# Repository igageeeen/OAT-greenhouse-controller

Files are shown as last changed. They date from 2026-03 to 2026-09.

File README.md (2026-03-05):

# ビニールハウス自動開閉制御システム

Raspberry Pi + Home Assistant を使ったビニールハウス開閉器の制御システムです。
スマートフォンから遠隔操作でき、温湿度・CO2 を常時モニタリングできます。

> **2026-03-01 メイカーズ長岡まつり 展示作品**
> OpenAgriTech

---

## 概要

| 項目 | 内容 |
|---|---|
| プラットフォーム | Raspberry Pi OS (Trixie) |
| UI | Home Assistant (Docker) |
| 外部公開 | Cloudflare Tunnel |
| センサ | SEN0501（温湿度）、SCD41（CO2・温湿度） |
| モータドライバ | Cytron MDD10 |
| モータ制御 | PWM 20kHz（GPIO18）+ 方向制御（GPIO23） |

---

## システム構成

```
スマートフォン
    ↓ HTTPS
Cloudflare Tunnel
    ↓
Home Assistant（Docker, host network）
    ↓ REST API（127.0.0.1）
┌───────────────────┬──────────────────────┐
│ metrics_server.py │   motor_server.py    │
│   :8124           │   :8125              │
│   温湿度・CO2取得  │   モータ開閉制御      │
└────────┬──────────┴──────────┬───────────┘
         │ I2C                 │ GPIO / PWM
    SEN0501 / SCD41         MDD10 → モータ
```

---

## ファイル構成

```
.
├── README.md                          # このファイル
├── docs/
│   ├── PARTS_LIST.md                  # パーツリスト（BOM）
│   └── SETUP.md                       # セットアップ手順
└── src/
    ├── metrics_server.py              # 環境センサ HTTP サーバ（:8124）
    ├── motor_server.py                # モータ制御 HTTP サーバ（:8125）
    ├── HomeAssistantConfiguration.yaml# Home Assistant 設定
    ├── SPEC.md                        # システム仕様書（詳細）
    └── ROM_USB_MIGRATION_PLAN.md      # SDカードROM化・USB分離計画
```

---

## 主な機能

- **遠隔開閉操作**: スマートフォンから「開く」「閉じる」「停止」ボタン操作
- **動作時間・出力の調整**: UI スライダーで秒数（1〜900秒）と PWM duty（0〜100%）を設定
- **環境モニタリング**: 温度・湿度（SEN0501）、CO2・温度・湿度（SCD41）を 30 秒間隔で取得
- **フェイルセーフ**: 最大 900 秒制限・ロックファイルによる二重起動防止・緊急停止 API

---

## セットアップ

詳細は [docs/SETUP.md](docs/SETUP.md) を参照してください。

### 必要なパーツ

[docs/PARTS_LIST.md](docs/PARTS_LIST.md) を参照してください。

### 依存ライブラリ（Python）

```bash
sudo pip install RPi.GPIO adafruit-circuitpython-scd4x dfrobot-environmental-sensor --break-system-packages

```

### サービス起動（systemd）

```bash
# metrics_server を登録・起動
sudo systemctl enable metrics_server
sudo systemctl start metrics_server

# motor_server を登録・起動
sudo systemctl enable motor_server
sudo systemctl start motor_server
```

---

## ネットワーク設計

- Home Assistant と各サーバはすべて `127.0.0.1` で通信
- LAN の IP アドレス変更やテザリング切り替えに依存しない設計
- 外部公開は Cloudflare Tunnel のみ（ポート開放不要）

---

## 耐障害性（ROM化・USB分離）

電源断を前提とした農業現場での運用のため、以下の対策を実施しています：

- root を `ro`（読み取り専用）でマウントし SD カードへの書き込みをゼロに
- journald を volatile（メモリのみ）、`/tmp` を tmpfs に
- Docker データ・Home Assistant DB・cloudflared データを USB フラッシュメモリへ分離
- 詳細: [src/ROM_USB_MIGRATION_PLAN.md](src/ROM_USB_MIGRATION_PLAN.md)

---

## ライセンス

MIT License

---

## 作成について

本プロジェクトのコード・ドキュメントは、**Claude（Anthropic 社製 AI アシスタント）の支援を受けて作成**しました。

- コード生成・レビュー・ドキュメント整備に Claude Code（claude-sonnet-4-6）、chatGPT5.2を使用
- 設計方針・要件定義・最終確認は人間（iga）が行っています

> *AI を農業 × ものづくりにどう活かすか、という実験でもあります。*

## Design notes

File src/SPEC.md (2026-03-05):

# ハウス開閉器システム仕様書

最終更新: 2026-02-23 08:42:50

------------------------------------------------------------------------

## 1. システム概要

本システムは Raspberry Pi 上で動作する
ハウス（ビニールハウス）開閉制御装置である。

Home Assistant を UI とし、 ローカル Python HTTP サーバ経由で

-   モータ制御
-   環境センサ取得

を行う。

外部公開は Cloudflare Tunnel 経由。

------------------------------------------------------------------------

## 2. 全体構成

\[スマホ\]\
　↓ (Cloudflare)\
\[Home Assistant (Docker, host network)\]\
　↓ REST\
\[motor_server.py :8125\]\
\[metrics_server.py :8124\]\
　↓\
\[Raspberry Pi GPIO / I2C\]

------------------------------------------------------------------------

## 3. 動作環境

-   Raspberry Pi OS (Trixie) ※2025年以降の標準リリース
-   Docker (Home Assistant)
-   network_mode: host
-   systemd 管理サービス
-   journald ログ最小化
-   ROM化済み（root ext4 を `ro` マウント、Docker・HA・cloudflared データは USB へ分離）

### GPIO / PWM 方式について

#### なぜ pigpio を使わないのか

Trixie（Pi5）環境では `pigpio` が**実質使用不可**であり、複数の問題が重なっている：

| 問題 | 技術的背景 |
|---|---|
| **Pi 5 でハードコード除外** | Pi5 は BCM2712 + RP1 サウスブリッジ構成。GPIO を管理するのは RP1 で、pigpio が依存する `/dev/mem` 経由の DMA アクセスが機能しない。pigpio はリビジョンコード未登録として `"unknown rev code"` で即時終了する |
| **Trixie でビルド不可** | pigpio の `setup.py` は Python の `distutils` モジュールに依存。Python 3.12（Trixie 標準）で `distutils` が標準ライブラリから削除され、Trixie には代替の `python3-distutils` パッケージも存在しない |
| **メンテナンス事実上終了** | 開発者（joan2937 氏）自身が Pi5 対応を「互換性を壊さずには不可能かもしれない巨大なタスク」と GitHub Issue で発言。Pi5 サポートの公式ロードマップなし |

#### なぜ RPi.GPIO を方向制御に使うのか

`RPi.GPIO` も Pi 5 では公式非対応（Raspberry Pi 公式が明言）だが：

-   本システムでは **方向制御（GPIO23 の HIGH/LOW 出力）のみ**に使用
-   Pi 4 系では引き続き動作する
-   **Pi 5 で使う場合は `rpi-lgpio`**（RPi.GPIO 互換の drop-in 代替）を `pip install rpi-lgpio` で追加インストールするとコード変更なしで動作する

#### GPIO ライブラリ全体像（2026年時点）

| ライブラリ | Pi4 | Pi5 | Trixie | PWM | 状況 |
|---|:---:|:---:|:---:|-----|---|
| `pigpio` | ○ | **×** | **×**（ビルド不可） | ハードウェア | 実質廃止 |
| `RPi.GPIO` | ○ | △（非公式） | △ | ソフトのみ | 非推奨移行中 |
| `rpi-lgpio` | ○ | ○ | ○ | ソフトのみ | RPi.GPIO drop-in 代替 |
| `lgpio` | ○ | ○ | ○ | ソフトのみ | Raspberry Pi 公式推奨 |
| `gpiozero` | ○ | ○ | ○ | ソフトのみ | 公式推奨（lgpio バックエンド） |
| `python-gpiod` | ○ | ○ | ○ | なし | Linux 標準（GPIO のみ） |
| **sysfs PWM** | **○** | **○** | **○** | **ハードウェア** | **精度 PWM に最善** |

→ モータ制御のように精度が必要な PWM には **sysfs ハードウェア PWM が最も安定**。
`dtoverlay=pwm` を `/boot/firmware/config.txt` に追記して有効化する。

------------------------------------------------------------------------

## 4. ディレクトリ構成（主要リソース）

```
.
├── README.md
├── docs/
│   ├── PARTS_LIST.md          # パーツリスト（BOM）
│   └── SETUP.md               # セットアップ手順
└── src/
    ├── HomeAssistantConfiguration.yaml
    ├── metrics_server.py
    ├── motor_server.py
    ├── SPEC.md                # このファイル
    └── ROM_USB_MIGRATION_PLAN.md
```

------------------------------------------------------------------------

## 5. センサ取得仕様

### 使用センサ

-   SEN0501（温湿度）I2C 0x22
-   SCD41（CO2 / 温湿度）I2C 0x62

### ポート

http://127.0.0.1:8124/metrics

### JSON形式

{ "timestamp": 1700000000, "sen0501": { "temperature_c": 20.1,
"humidity_rh": 40.2 }, "scd41": { "co2_ppm": 900, "temperature_c": 19.9,
"humidity_rh": 41.0 } }

------------------------------------------------------------------------

## 6. モータ制御仕様

### GPIO割当

-   DIR: GPIO23
-   PWM: GPIO18 (pwmchip0 / CH0)
-   周波数: 20kHz
-   最大動作時間: 900秒

### API仕様

開閉: GET /run?dir=0\|1&sec=秒数&duty=0-100

停止: GET /stop

ヘルスチェック: GET /health

------------------------------------------------------------------------

## 7. フェイルセーフ設計

### 過走防止の二重構成

| レイヤ | 機構 | 説明 |
|---|---|---|
| **ハードウェア** | モータ内蔵機械式リミットスイッチ | 設定回転数に達すると内部ギヤがスイッチに接触し、内部回路を遮断・自動停止。赤/緑ダイヤルで開閉幅（回転数）を調節 |
| **ソフトウェア** | 最大動作時間 900秒制限 | `motor_run()` の `MAX_SECONDS` で上限を強制。ハードが万一機能しなくても時間でカット |

### その他フェイルセーフ

-   lockファイルによる二重起動防止（`/run/house-motor.lock`）
-   `finally` で必ず `motor_stop` 実行（例外・タイムアウト問わず停止）
-   GPIO cleanup 実施

------------------------------------------------------------------------

## 8. ネットワーク設計

-   HAは Docker host network
-   すべて 127.0.0.1 通信
-   LAN IP 変更に依存しない
-   テザリング時も動作

------------------------------------------------------------------------

## 9. 運用方針

-   緊急停止は物理的遮断を優先
-   stop APIは補助的扱い
-   ログは最小化（ROM化前提）
-   systemd自動再起動

------------------------------------------------------------------------

## 10. 今後の改善候補

-   ThreadingHTTPServer化（非同期停止対応）
-   PWMハードウェア初期化強化
-   異常検知通知
-   モータ電流監視

------------------------------------------------------------------------

以上

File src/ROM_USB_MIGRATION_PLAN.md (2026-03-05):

# ハウス開閉器 ROM化・USB分離構成まとめ

作成日時: 2026-02-23 09:11:38

------------------------------------------------------------------------

## 1. 背景

本システムは電源断（コンセント抜去）を前提とした運用環境で使用される。
従来構成ではSDカード上に

-   OS
-   Docker
-   Home Assistant DB

が存在し、電源断による破損リスクが高かった。

そのため以下の方針に変更する。

------------------------------------------------------------------------

## 2. 新構成方針

### SDカード（最小書き込み）

-   Raspberry Pi OS
-   systemd
-   最小ログ（volatile）

### USBフラッシュメモリ

-   Docker data-root
-   Home Assistant config（DB含む）
-   cloudflared 設定（`/mnt/hausb/cloudflared/`）

構成例：

SD: / /boot（ro）

USB: /mnt/hausb/docker /mnt/hausb/ha_config /mnt/hausb/cloudflared

------------------------------------------------------------------------

## 3. 実施内容

### 3.0 USB の UUID 確認とマウントポイント作成

USB を接続した状態で UUID を確認する：

```bash
sudo blkid
# 例: /dev/sda1: UUID="xxxx-xxxx" TYPE="ext4"
```

マウントポイントを作成：

```bash
sudo mkdir -p /mnt/hausb
```

`/etc/fstab` に以下をすべて反映する（root の ro 化・USB マウント）：

```bash
sudo nano /etc/fstab
```

```
# SD カード root を読み取り専用（ROM化）
# PARTUUID は "sudo blkid /dev/mmcblk0p2" で確認
PARTUUID=xxxxxxxx-02  /  ext4  ro,noatime  0  1

# USB フラッシュメモリ（Docker・HA・cloudflared データ用）
UUID=xxxx-xxxx  /mnt/hausb  ext4  defaults,noatime,nofail  0  2
```

> - root を `ro` にすると `/` への書き込みはすべてエラーになります。メンテナンス時は `sudo mount -o remount,rw /` で一時的に rw に戻してください。
> - `nofail` を付けることで USB が接続されていなくても起動が止まらなくなります。

マウントを確認：

```bash
sudo mount /mnt/hausb
df -h | grep hausb
```

------------------------------------------------------------------------

### 3.1 DockerデータをUSBへ移動

```bash
# 1. Docker 停止
sudo systemctl stop docker

# 2. USB へ rsync（進捗表示あり）
sudo rsync -avP /var/lib/docker/ /mnt/hausb/docker/

# 3. daemon.json に data-root 指定
sudo mkdir -p /etc/docker
sudo nano /etc/docker/daemon.json
```

```json
{
  "data-root": "/mnt/hausb/docker"
}
```

```bash
# 4. Docker 再起動
sudo systemctl start docker

# 5. Root Dir 確認（/mnt/hausb/docker と表示されれば OK）
docker info | grep "Docker Root Dir"
```

------------------------------------------------------------------------

### 3.2 Home Assistant config移動

```bash
# 1. HA コンテナ停止
docker stop homeassistant

# 2. USB へコピー
sudo mkdir -p /mnt/hausb/ha_config
sudo cp -a /home/$USER/ha_config/. /mnt/hausb/ha_config/

# 3. コンテナを USB パスで再作成
docker rm homeassistant
docker run -d \
  --name homeassistant \
  --restart unless-stopped \
  --network host \
  -v /mnt/hausb/ha_config:/config \
  ghcr.io/home-assistant/home-assistant:stable
```

------------------------------------------------------------------------

### 3.3 cloudflared の書き込み先を USB へ（systemd override）

cloudflared は `$HOME/.cloudflared/` に認証情報やランタイムファイルを書き込む。
root の ro 化に備えて（再起動前に実施）、systemd override で `HOME` を USB に向けることで書き込み先を USB に移す。

```bash
# 1. override ディレクトリ作成
sudo mkdir -p /etc/systemd/system/cloudflared.service.d

# 2. override ファイル作成
sudo nano /etc/systemd/system/cloudflared.service.d/override.conf
```

```ini
[Service]
Environment=HOME=/mnt/hausb/cloudflared
WorkingDirectory=/mnt/hausb/cloudflared
```

```bash
# 3. USB 側にディレクトリ作成
sudo mkdir -p /mnt/hausb/cloudflared

# 4. 既存の認証情報があれば移行
#    （token ベースのインストールのみの場合は不要）
# sudo cp -a ~/.cloudflared/. /mnt/hausb/cloudflared/.cloudflared/

# 5. 設定を反映して再起動
sudo systemctl daemon-reload
sudo systemctl restart cloudflared
sudo systemctl status cloudflared
```

> `/etc/systemd/system/cloudflared.service.d/override.conf` は root 上（ro）に置かれるが、
> 内容は変わらないため問題なし。トークン更新時は `sudo mount -o remount,rw /` で一時的に rw に戻す。

------------------------------------------------------------------------

## 4. 自動起動方式の整理

USB 依存構成では **USB マウント後に Docker・HA が起動する**ことを保証する必要があります。

### systemd による管理（推奨）

`/etc/systemd/system/homeassistant.service` を作成：

```ini
[Unit]
Description=Home Assistant
After=network-online.target docker.service
RequiresMountsFor=/mnt/hausb
Requires=docker.service

[Service]
Restart=always
RestartSec=10
ExecStart=/usr/bin/docker start -a homeassistant
ExecStop=/usr/bin/docker stop homeassistant

[Install]
WantedBy=multi-user.target
```

```bash
# Docker の自動再起動ポリシーを無効化（systemd に任せる）
docker update --restart no homeassistant

sudo systemctl daemon-reload
sudo systemctl enable homeassistant
sudo systemctl start homeassistant
```

> `RequiresMountsFor=/mnt/hausb` により、USB がマウントされていない場合はサービスが起動しません。

------------------------------------------------------------------------

> **3〜4節の全作業（Docker・HA・cloudflared の USB 移設）完了後に再起動してください（セクション 5 参照）。**

## 5. ログおよび書き込み削減

### journald を volatile（メモリのみ）に設定

```bash
sudo nano /etc/systemd/journald.conf
```

```ini
[Journal]
Storage=volatile
```

```bash
sudo systemctl restart systemd-journald
```

### /tmp を tmpfs に

3.0 の fstab 編集時に以下もあわせて追記：

```
tmpfs  /tmp  tmpfs  defaults,noatime,size=64m  0  0
```

### root を読み取り専用（ro）にする

3.0 の fstab で root に `ro` を設定済みであれば完了。
変更後は一度再起動して ro で正常起動することを確認する：

```bash
sudo reboot
# 再起動後
mount | grep " / "
# → "ro" が含まれていれば OK
```

> root が ro の状態で書き込みが必要な操作（パッケージ更新など）は
> `sudo mount -o remount,rw /` で一時的に rw に戻してから実施し、
> 完了後に `sudo mount -o remount,ro /` で ro に戻す。

### その他

-   HA recorder 最小化（`HomeAssistantConfiguration.yaml` の `recorder` セクション参照）

これによりSD書き込みを最小化。

------------------------------------------------------------------------

## 6. 期待効果

-   SDカード破損リスク大幅低減
-   Docker破損時もUSB側のみ影響
-   OS自体は生存可能
-   電源断環境での耐久性向上

------------------------------------------------------------------------

## 7. 今後の発展案

-   overlayfs導入（ro root + 差分書き込み層による完全保護）
-   定期バックアップ自動化
-   SSD化による耐久性向上

------------------------------------------------------------------------

以上

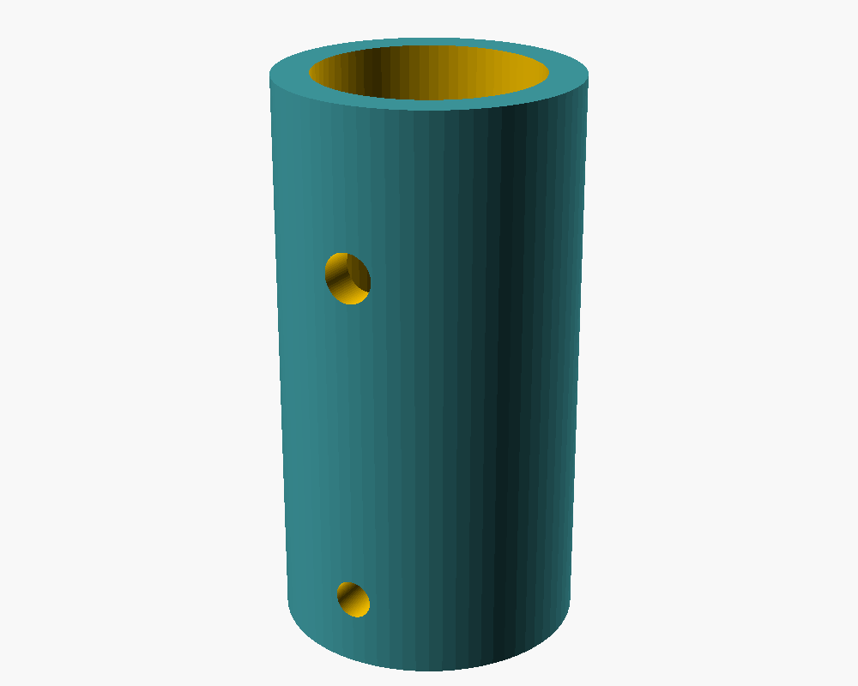
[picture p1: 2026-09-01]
hardware/demo-stand/preview_coupler.png

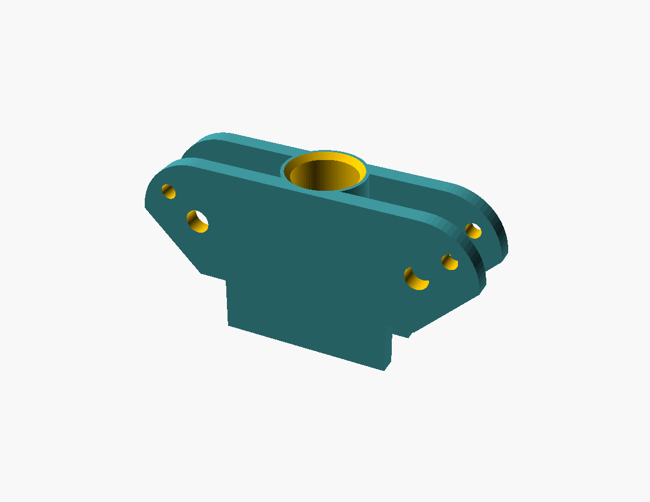
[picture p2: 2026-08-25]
hardware/demo-stand/preview_pole_clamp.png

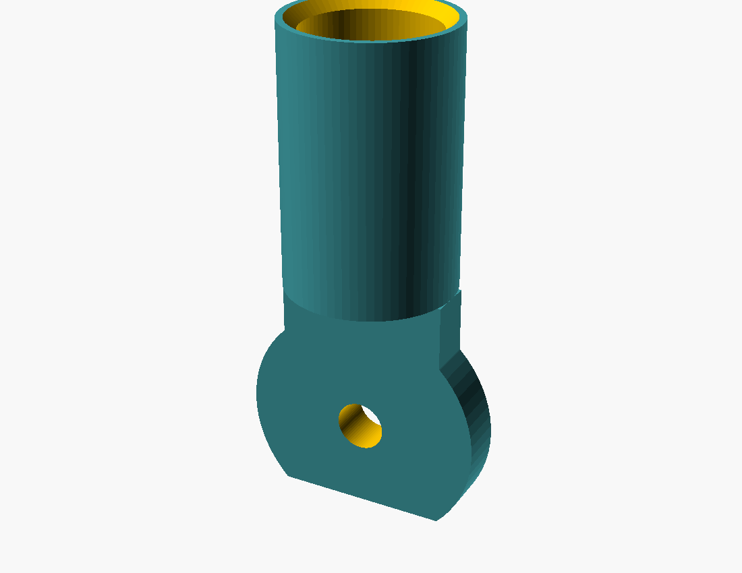
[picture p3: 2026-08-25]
hardware/demo-stand/preview_arm.png

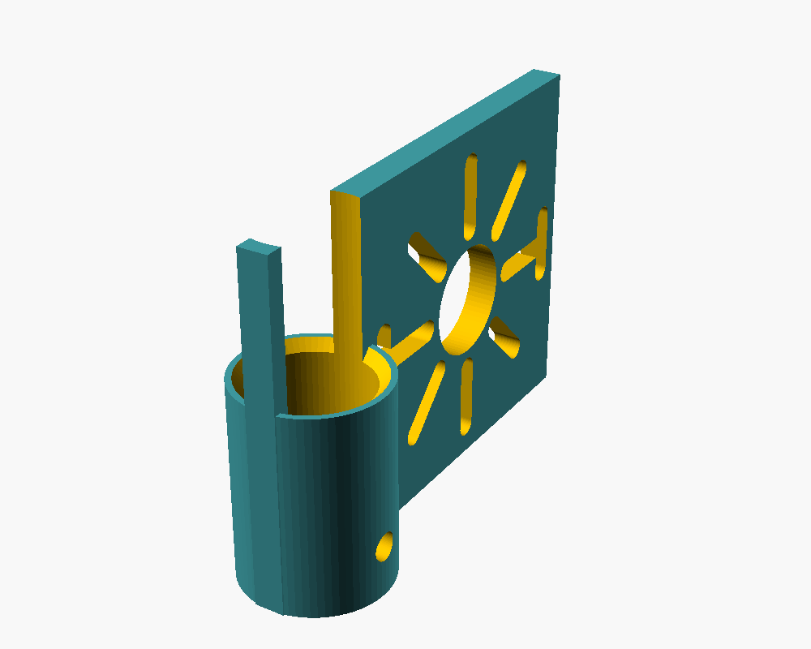
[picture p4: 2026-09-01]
hardware/demo-stand/preview_motor_plate.png

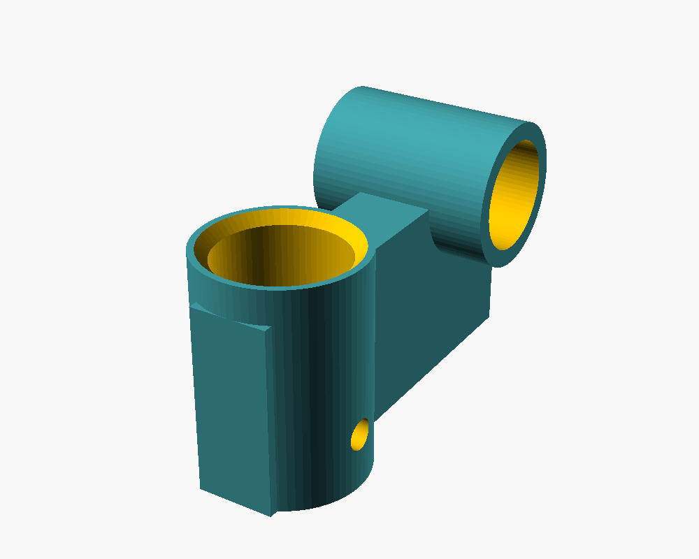
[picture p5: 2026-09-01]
hardware/demo-stand/preview_bearing_block.png

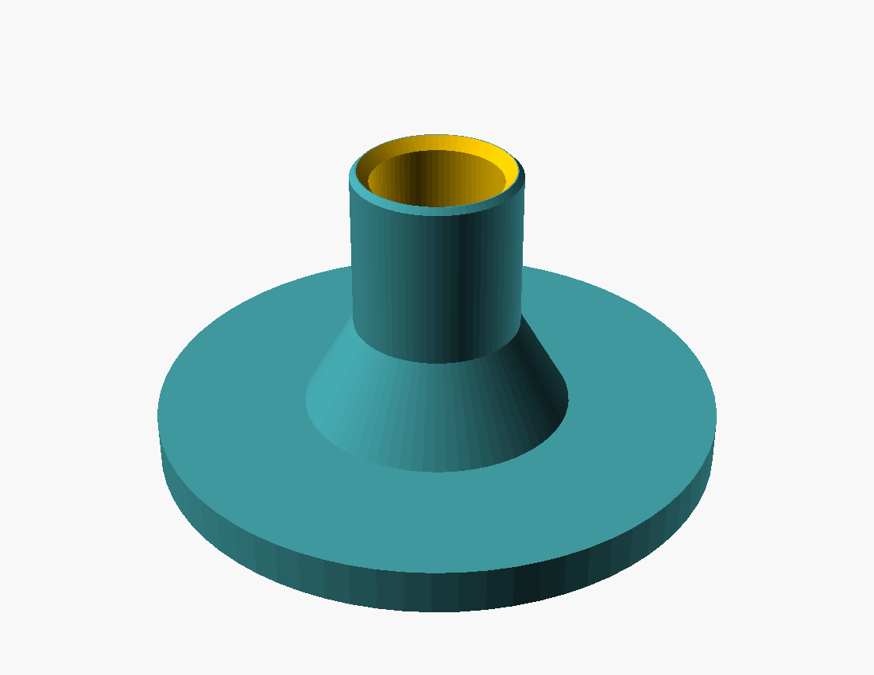
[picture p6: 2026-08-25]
hardware/demo-stand/preview_foot.png

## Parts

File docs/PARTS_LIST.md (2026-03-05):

# パーツリスト（BOM）

ビニールハウス自動開閉制御システム

> このドキュメントは Claude（Anthropic）の支援を受けて作成しました。
> 価格・在庫は作成時点（2026-02 頃）の参考値です。変動する場合があります。

---

## メインボード

| 部品名 | 型番・仕様 | 数量 | 備考 |
|---|---|---|---|
| Raspberry Pi | Raspberry Pi 4B または 5 推奨 | 1 | GPIO・I2C・PWM 使用 |
| SD カード | 16GB 以上（Class 10 推奨） | 1 | OS 用。書き込み最小化運用 |
| USB フラッシュメモリ | 32GB 以上（USB 3.0 推奨） | 1 | Docker・HA データ保管用 |
| 電源アダプタ | 5V / 3A 以上（Raspberry Pi 公式推奨） | 1 | |

---

## センサ

| 部品名 | 型番 | I2C アドレス | 数量 | 備考 |
|---|---|---|---|---|
| 温湿度センサ | DFRobot SEN0501 | 0x22 | 1 | 温度・湿度 |
| CO2・温湿度センサ | Sensirion SCD41 | 0x62 | 1 | CO2・温度・湿度 |

---

## モータ制御

| 部品名 | 型番・仕様 | 数量 | 備考 |
|---|---|---|---|
| モータドライバ | Cytron MDD10 | 1 | PWM 20kHz 対応、デュアルチャンネル |
| DC 電動ロールアップモータ | 農業用ビニールハウス巻き上げ機（中華OEM品。型番なし） 24V / 約100W | 1 | Amazon / AliExpress で「電動 ビニールハウス 巻き上げ 24V」等で検索。外部配線は2線（+/-）のみ。**内部に機械式リミットスイッチ内蔵**：設定回転数に達すると内部ギヤがスイッチに接触し内部回路を遮断・自動停止（ダイヤルで開閉幅を調節）。ソフトの最大動作時間制限と合わせて二重の過走防止になる。定格電流 約4.2A、起動突入電流最大 約20A。MDD10 の 10A連続 / 30Aピーク 以内 |

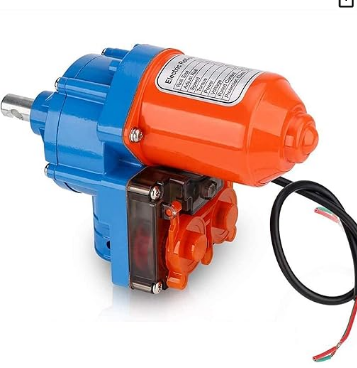
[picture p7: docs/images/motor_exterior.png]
モータ外観
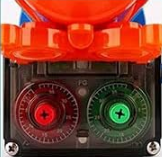
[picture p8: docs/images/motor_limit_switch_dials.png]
リミットスイッチ調節ダイヤル
 

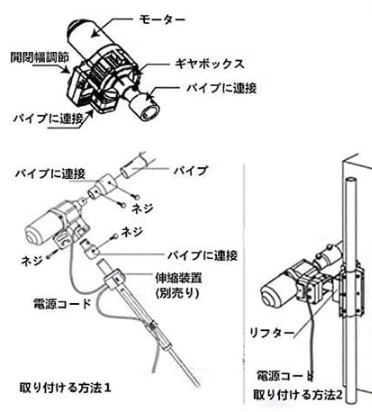
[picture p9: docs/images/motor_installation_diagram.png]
取り付け図
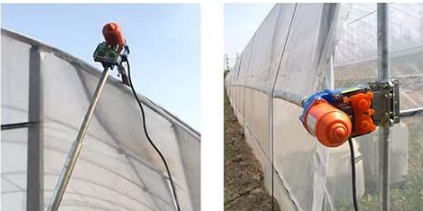
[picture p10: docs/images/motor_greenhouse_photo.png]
実際のビニールハウスへの取り付け
 

---

## 電源

> **⚠️ 100V AC 配線には第二種電気工事士の資格が必要です**
>
> スイッチング電源の AC 入力側（コンセント〜電源端子台）への配線は
> 電気工事士法により **第二種電気工事士以上の資格を持つ者が実施**する必要があります。
> 無資格での AC 配線は違法であり、火災・感電の危険があります。

| 部品名 | 型番・仕様 | 数量 | 備考 |
|---|---|---|---|
| Raspberry Pi 用電源アダプタ | 5V / 3A 以上（USB-C）Raspberry Pi 公式推奨 | 1 | Pi のみ専用。モータ電源と別系統 |
| モータ用スイッチング電源 | Mean Well LRS-350-24（24V / 14.6A / 350W） | 1 | AC100-240V 入力、DC24V 出力。MDD10 電源 |

---

## 配線・端子材料

### 配線径の目安

| 区間 | 電線規格（AWG） | 備考 |
|---|---|---|
| AC 100V 入力（コンセント〜電源） | **AWG 14**（2.0mm²）以上 | 要電工2種。最大電流に応じて選定 |
| DC 24V 主回路（電源〜MDD10） | **AWG 16**（1.25mm²） | 定格 4.2A、起動電流最大 約20A。AWG 16 の許容電流 13A で通常運用は十分 |
| DC 24V モータ出力（MDD10〜モータ） | **AWG 16**（1.25mm²） | 同上。長配線の場合は電圧降下を考慮して AWG 14 に拡大 |
| GPIO 信号線（Pi〜MDD10 DIR/PWM） | AWG 26（ジャンパワイヤ標準） | 低電流信号線 |
| I2C（Pi〜センサ） | AWG 26〜28 | 低電流信号線 |
| アース（保護接地） | **AWG 14** 以上、黄緑色 | スイッチング電源ケースに接続 |

### 端子・接続材料

| 部品名 | 仕様 | 備考 |
|---|---|---|
| 絶縁被覆付丸端子 | 対応電線径・ネジ径に合わせて選定 | AC 配線・アース線の固定に使用 |
| 棒端子（フェルール端子） | 対応電線径に合わせて選定 | MDD10・電源端子台の差し込み接続に使用 |
| コルゲートチューブ | 内径 10〜15mm 程度 | 配線保護・まとめ用 |
| ジャンパワイヤ | オス-メス / メス-メス | GPIO 接続用 |
| I2C ケーブル | 4線（SDA / SCL / VCC / GND） | センサ接続用（2本） |

### 筐体

| 部品名 | 仕様 | 備考 |
|---|---|---|
| 電気工事用プラスチックボックス | IP54 以上推奨（屋外・農場用途） | 各基板・電源を収容。穴あけ加工が必要な場合あり |

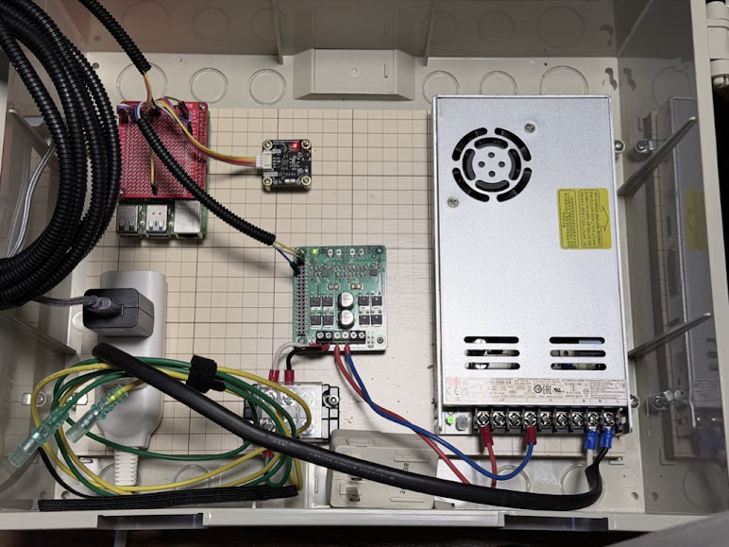
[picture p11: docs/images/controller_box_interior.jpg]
制御ボックス内部


---

## GPIO 割当

| GPIO（BCM） | 用途 |
|---|---|
| GPIO 18 | PWM 出力（モータ速度制御、20kHz） |
| GPIO 23 | DIR 出力（モータ回転方向） |
| SDA (GPIO 2) | I2C データ |
| SCL (GPIO 3) | I2C クロック |

---

## ソフトウェア（無償）

| ソフトウェア | 用途 |
|---|---|
| Raspberry Pi OS (Trixie) | OS |
| Docker | Home Assistant コンテナ実行 |
| Home Assistant | UI・制御ハブ |
| Cloudflare Tunnel | 外部公開（無料プラン） |
| Python 3 | metrics_server / motor_server |

### Python ライブラリ

```bash
sudo pip install RPi.GPIO adafruit-circuitpython-scd4x dfrobot-environmental-sensor --break-system-packages
```

---

## 注意事項

- **AC 100V 配線は第二種電気工事士以上の有資格者が実施してください。**（電気工事士法）
- モータ用電源（24V）と Raspberry Pi 用電源（5V）は**別系統・別アダプタ**にしてください。
- 棒端子はかしめ工具（フェルールクリンパー）を使用して圧着してください。手でのねじ込みは緩みの原因になります。
- MDD10 の PWM 入力は 3.3V ロジックに対応していますが、接続前にデータシートを確認してください。
- SCD41 は起動後約 5 秒で最初の測定値が得られます（`data_ready` フラグ確認）。
- スイッチング電源（LRS-350-24）のケースは**保護接地（アース）**を必ず接続してください。

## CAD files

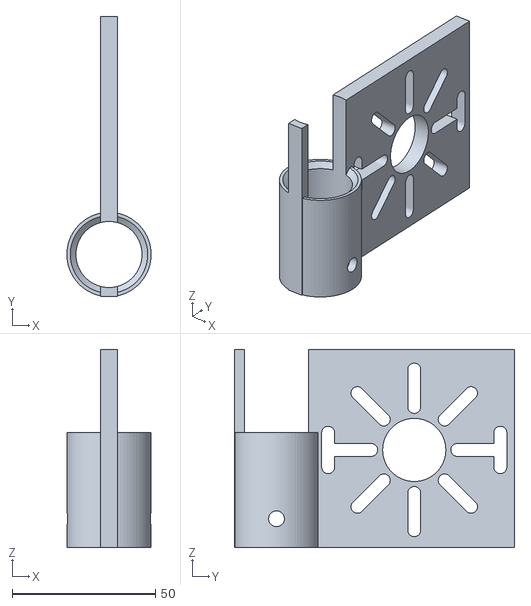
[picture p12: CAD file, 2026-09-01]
hardware/demo-stand/motor_plate.stl
29.4 x 97.7 x 69.0

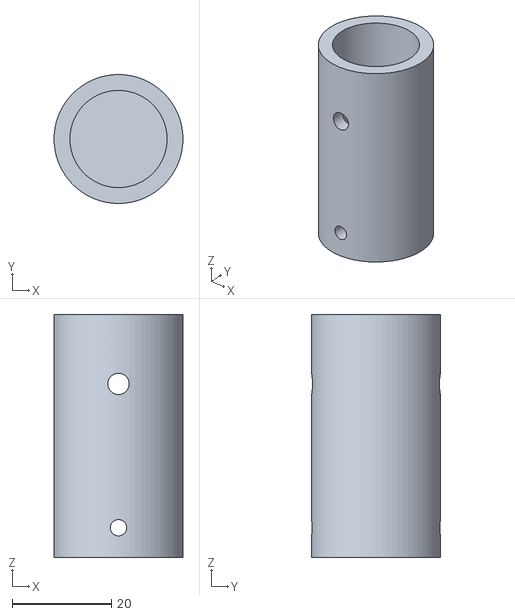
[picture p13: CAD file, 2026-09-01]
hardware/demo-stand/coupler.stl
26.0 x 26.0 x 49.0

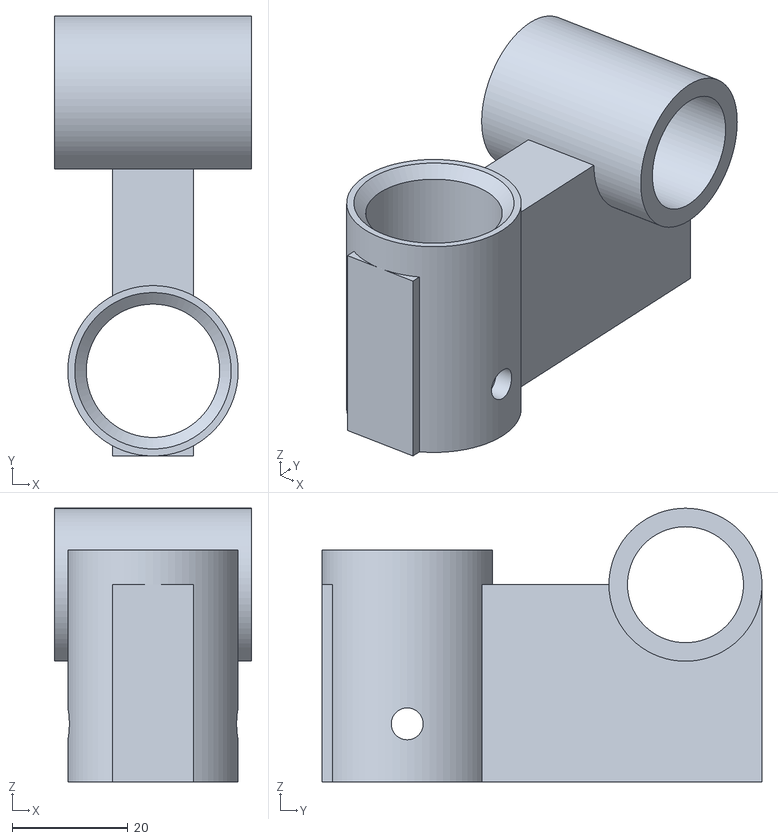
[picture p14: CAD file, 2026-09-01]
hardware/demo-stand/bearing_block.stl
34.0 x 75.9 x 47.2

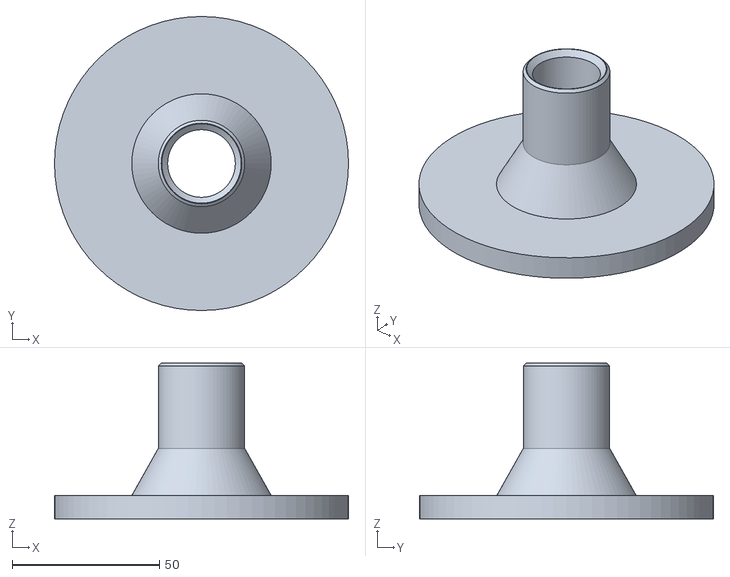
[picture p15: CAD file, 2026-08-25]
hardware/demo-stand/foot.stl
100.0 x 100.0 x 53.0

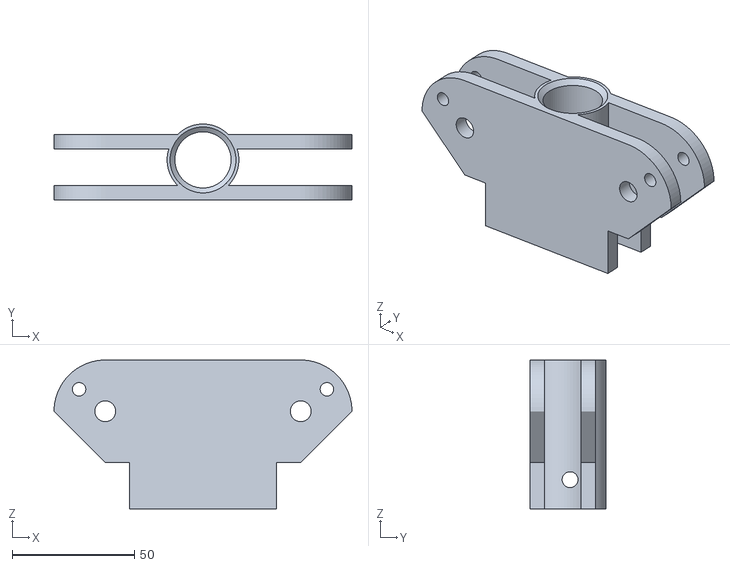
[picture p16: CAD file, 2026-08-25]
hardware/demo-stand/pole_clamp.stl
122.0 x 31.1 x 61.0

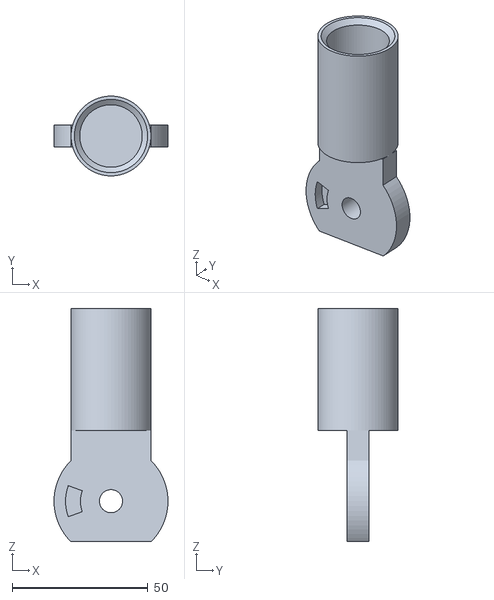
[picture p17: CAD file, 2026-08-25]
hardware/demo-stand/arm.stl
42.0 x 29.4 x 85.8

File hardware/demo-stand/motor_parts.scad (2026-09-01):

/* ============================================================
   Roll-up drive fixtures for the maker-faire demo   (rev.1)
   Printer : Bambu Lab P1S      Material : PLA

   Drive train
     5840-31ZY worm gear motor, DC12V 30RPM, 8mm D output shaft
     (output shaft is at RIGHT ANGLES to the motor body)
       -> coupler -> 19mm winding pipe, carrying a 50x60cm sheet
     Support posts are 22mm pipe.

   All three parts print standing on the collar axis: flat base on
   the plate, no support, and every bore that matters is vertical.

   Render:  openscad -D part="motor_plate" -o motor_plate.stl motor_parts.scad
     "motor_plate"    - clamps a 22mm post, motor bolts/straps to it
     "bearing_block"  - clamps a 22mm post, journals the 19mm pipe
     "coupler"        - 8mm D shaft -> 19mm pipe
     "assembly"       - layout preview
   ============================================================ */

part = "assembly";

// ---- pipes -------------------------------------------------
post_od   = 22.2;   // support post
roll_od   = 19.1;   // winding pipe
wall      = 3.2;

// ---- motor (5840-31ZY) ------------------------------------
// VERIFY THESE THREE WITH CALIPERS BEFORE PRINTING THE COUPLER:
shaft_d    = 8.0;   // output shaft diameter
shaft_flat = 7.3;   // across the D flat
shaft_len  = 14;    // how far the shaft stands off the gearbox face

// ---- layout ------------------------------------------------
// the winding pipe runs alongside the post, offset by axis_off.
// 48mm keeps the outer end of the bolt slots clear of the collar and
// leaves the 40mm-wide gearbox well clear of the post.
axis_off  = 48;
collar_h  = 40;
pin_d     = 5.5;    // M5 pin, drilled through the post
plate_t   = 6;
plate_w   = 70;     // motor plate is square-ish, plate_w x plate_w

post_id   = post_od + 0.8;
post_ring = post_id + wall * 2;
roll_run  = roll_od + 0.9;          // running clearance in the journal
roll_grip = roll_od + 0.5;          // grip fit in the coupler
jour_od   = roll_run + wall * 2;

axis_z    = collar_h - 6;           // shaft / journal height on the collar

$fn = 72;

// ============================================================
// shared: collar that slides onto the 22mm post and is pinned
// through a hole drilled in the pipe
// ============================================================
module post_collar(h = collar_h) {
    difference() {
        cylinder(d = post_ring, h = h);
        translate([0, 0, -1]) cylinder(d = post_id, h = h + 2);
        // lead-in so the post starts easily (45deg, self-supporting)
        translate([0, 0, h - 2]) cylinder(d1 = post_id, d2 = post_id + 4, h = 2.01);
        // M5 cross pin, low down and clear of everything above
        translate([0, 0, 10]) rotate([0, 90, 0])
            cylinder(d = pin_d, h = 200, center = true);
    }
}

// ============================================================
// PART 1 : BEARING BLOCK
// A web wall rises from the plate and the journal sits on top of
// it, so the underside of the journal bore is printed solid from
// below - which is exactly the surface the pipe rests on.
// ============================================================
module bearing_block(jour_len = 34, web_t = 14) {
    difference() {
        union() {
            post_collar();
            // supporting web: a slab standing on the bed
            translate([-web_t / 2, -post_ring / 2, 0])
                cube([web_t, axis_off + jour_od / 2 + post_ring / 2, axis_z]);
            translate([0, axis_off, axis_z]) rotate([0, 90, 0])
                cylinder(d = jour_od, h = jour_len, center = true);
        }
        // bore right through the whole part, not just the collar, so the
        // post may run on past it - these can sit anywhere on the pipe
        translate([0, 0, -1]) cylinder(d = post_id, h = 200);
        translate([0, 0, 10]) rotate([0, 90, 0])
            cylinder(d = pin_d, h = 200, center = true);
        // the journal itself, through-bored
        translate([0, axis_off, axis_z]) rotate([0, 90, 0])
            cylinder(d = roll_run, h = 200, center = true);
    }
}

// ============================================================
// PART 2 : MOTOR PLATE
// The gearbox face bolts flat against this plate. The 5840-31ZY
// has four M4 holes but the pitch is not published, so the plate
// carries eight radial SLOTS instead - any square or rectangular
// pattern with a half-diagonal between 15 and 28mm lands on them.
// If the real pattern misses, two strap slots let you simply
// zip-tie the gearbox down instead.
// ============================================================
module motor_plate() {
    difference() {
        union() {
            post_collar();
            // the plate: a vertical slab, normal along the shaft axis.
            // It runs all the way back past the collar so the two are
            // properly fused - the motor hangs off this joint.
            translate([-plate_t / 2, -post_ring / 2, 0])
                cube([plate_t, axis_off + plate_w / 2 + post_ring / 2,
                      axis_z + plate_w / 2]);
        }
        // bore right through the whole part, not just the collar, so the
        // post may run on past it - these can sit anywhere on the pipe
        translate([0, 0, -1]) cylinder(d = post_id, h = 200);
        translate([0, 0, 10]) rotate([0, 90, 0])
            cylinder(d = pin_d, h = 200, center = true);
        translate([0, axis_off, axis_z]) rotate([0, 90, 0]) {
            // clearance for the shaft and its boss - pure clearance, so
            // the droop of a horizontal bore does not matter here
            cylinder(d = 22, h = 200, center = true);
            // eight radial M4 slots
            for (a = [0 : 45 : 359]) rotate([0, 0, a])
                hull() for (r = [15, 28])
                    translate([r, 0, 0]) cylinder(d = 4.5, h = 200, center = true);
            // strap slots for a zip tie round the gearbox
            for (s = [-1, 1]) translate([0, s * 30, 0])
                hull() for (x = [-6, 6])
                    translate([x, 0, 0]) cylinder(d = 4.5, h = 200, center = true);
        }
    }
}

// ============================================================
// PART 3 : COUPLER   8mm D shaft -> 19mm pipe
// The D flat carries the torque; the M4 cross bolt through the
// pipe stops it slipping, and a second cross screw stops the
// coupler walking off the shaft.
// ============================================================
module coupler(grip_len = 30, web = 7) {
    d_depth = shaft_len - 2;
    total   = d_depth + web + grip_len;
    od      = roll_grip + wall * 2;
    difference() {
        cylinder(d = od, h = total);
        // D bore for the motor shaft (at the bottom in print orientation).
        // The flat sits shaft_flat away from the far side of the circle,
        // i.e. (shaft_flat - shaft_d/2) below centre, plus a little slack.
        translate([0, 0, -1]) intersection() {
            cylinder(d = shaft_d + 0.3, h = d_depth + 1);
            translate([-10, -(shaft_flat - shaft_d / 2) - 0.15, 0])
                cube([20, 20, d_depth + 1]);
        }
        // socket for the winding pipe
        translate([0, 0, d_depth + web]) cylinder(d = roll_grip, h = grip_len + 1);
        // M4 through the pipe - drill the pipe to match
        translate([0, 0, total - 14]) rotate([90, 0, 0])
            cylinder(d = 4.3, h = 200, center = true);
        // M4 set screw onto the D flat
        translate([0, 0, d_depth / 2]) rotate([90, 0, 0])
            cylinder(d = 3.3, h = 200, center = true);
    }
}

// ============================================================
if (part == "bearing_block") bearing_block();
else if (part == "motor_plate") motor_plate();
else if (part == "coupler") coupler();
else if (part == "assembly") {
    motor_plate();
    translate([0, 0, 0]) color("orange")
        translate([-40, axis_off, axis_z]) rotate([0, 90, 0]) coupler();
    translate([260, 0, 0]) bearing_block();
    // winding pipe
    color("silver") translate([-10, axis_off, axis_z]) rotate([0, 90, 0])
        cylinder(d = roll_od, h = 300);
}

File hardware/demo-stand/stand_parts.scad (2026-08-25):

/* ============================================================
   Greenhouse demo stand - printable footing parts  (rev.2)
   Printer : Bambu Lab P1S      Material : PLA
   Pipe    : greenhouse hoop pipe, OD 22.2mm

   rev.2 changes
     - pole_clamp is now a two-sided FORK: one clamp anywhere on
       the pole carries BOTH the fore and aft outrigger arms.
     - every part is shaped for its print orientation: flat base
       on the plate, no support anywhere, all downward faces >=45
       degrees, and the load pressed ACROSS layers (compression)
       rather than pulling them apart.

   Render one part at a time:  openscad -D part="foot" -o foot.stl
   ============================================================ */

part = "assembly";

// ---------------- pipe / fit ----------------
pipe_od   = 22.2;
clear     = 0.40;   // per side. vertical bores print slightly under
wall      = 3.2;    // 8 perimeters @ 0.4mm nozzle
socket_id = pipe_od + clear * 2;
socket_od = socket_id + wall * 2;

// ---------------- joint geometry ----------------
paddle_t  = 8;                    // arm paddle thickness
fork_gap  = paddle_t + 0.8;       // slip clearance inside the fork
plate_t   = 6;                    // each fork plate
plate_y   = fork_gap / 2;         // inner face of each plate

pr        = 21;   // pivot head radius (both clamp plates and arm paddle)
boss_x    = 40;   // pivot offset from the pole axis - keeps the swinging
                  // arm's paddle (radius pr) clear of the collar
boss_z    = 40;   // pivot height
pivot_d   = 8.5;  // M8 clearance
index_d   = 5.5;  // M5 clearance
index_r   = 14;   // index radius (clamp hole / arm slot)
index_a   = 40;   // clamp's fixed index hole direction, deg from +X
sweep     = 40;   // total adjustable spread, deg

// the collar must reach the full height of the plates, otherwise the top
// few mm of plate would close over the bore and the pole could not pass
collar_h  = boss_z + pr;
pin_z     = 12;   // M6 through-pin height
pin_d     = 6.5;

skirt_z   = boss_z - pr;          // where the 45deg skirt meets the head
skirt_w1  = 30;                   // skirt half width. Capped so the tube of
                                  // an arm set to the narrowest spread still
                                  // swings past it with ~5mm to spare.
over45    = 0.45;                 // extra clearance factor, unused knob

$fn = 72;

// ============================================================
// helpers
// ============================================================

// bore that opens downward on the build plate: the first layers are
// squashed outward (elephant's foot), so relieve the very bottom
module relieved_bore(d, h, relief = 0.6, relief_h = 0.8) {
    cylinder(d = d, h = h);
    translate([0, 0, -0.01]) cylinder(d = d + relief * 2, h = relief_h);
}

// 45deg lead-in at the top of a bore so the pipe starts easily.
// Widening upward at 45deg is self-supporting.
module bore_leadin(d, z, c = 2) {
    translate([0, 0, z - c]) cylinder(d1 = d, d2 = d + c * 2, h = c + 0.01);
}

// ============================================================
// PART 1 : FOOT   (prints flange-down, no support)
// The pipe passes right through and its steel end bears on the
// floor - the printed disc only widens the footprint, so PLA
// never carries the standing load.
// ============================================================
module foot(base_d = 100, base_t = 8, socket_h = 45, gusset_h = 16) {
    total_h = base_t + socket_h;
    difference() {
        union() {
            // flat, unbroken bottom: best bed adhesion and least warp
            cylinder(d = base_d, h = base_t);
            // cone narrowing upward - self-supporting, and it is the
            // gusset that carries the tipping moment into the disc
            translate([0, 0, base_t])
                cylinder(d1 = socket_od + 18, d2 = socket_od, h = gusset_h);
            translate([0, 0, base_t + gusset_h])
                cylinder(d = socket_od, h = socket_h - gusset_h);
        }
        translate([0, 0, -1]) relieved_bore(socket_id, total_h + 2);
        bore_leadin(socket_id, total_h);
        // break the sharp top rim (chamfer pointing down-inward is fine,
        // it is a tiny feature on a vertical wall)
        translate([0, 0, total_h - 1])
            difference() {
                cylinder(d = socket_od + 4, h = 1.2);
                cylinder(d1 = socket_od, d2 = socket_od - 2.4, h = 1.2);
            }
    }
}

// ============================================================
// PART 2 : POLE CLAMP  (prints collar-up, no support)
// Two parallel plates straddle the pole and reach out to BOTH
// sides, so a single clamp carries a fore and an aft arm in
// double shear. Slide it to any height on the pole, drill one
// M6 hole through the pipe and pin it.
// ============================================================

// 2D outline of one fork plate, in the XZ plane
module plate_profile() {
    difference() {
        union() {
            // stadium joining the two pivot heads
            hull() {
                translate([ boss_x, boss_z]) circle(r = pr);
                translate([-boss_x, boss_z]) circle(r = pr);
            }
            // skirt down to the build plate. Straight vertical walls, not
            // a taper: zero overhang, and it more than doubles the bed
            // contact compared with a 45deg skirt. Its width is capped by
            // what the arm needs to swing past at the narrowest setting.
            translate([-skirt_w1, 0]) square([skirt_w1 * 2, skirt_z]);
        }
        // trim the lower-outboard quarter of each head back to 45deg,
        // otherwise the underside of the circle is an unprintable
        // near-horizontal overhang. It also opens the space the arm
        // swings through.
        for (s = [1, -1]) scale([s, 1])
            polygon([[boss_x, skirt_z], [boss_x + 60, skirt_z + 60],
                     [boss_x + 60, -1], [boss_x, -1]]);
    }
}

module pole_clamp() {
    difference() {
        union() {
            cylinder(d = socket_od, h = collar_h);
            for (s = [1, -1])
                translate([0, s * (plate_y + plate_t), 0])
                    rotate([90, 0, 0])
                        linear_extrude(plate_t) plate_profile();
        }
        // pole bore
        translate([0, 0, -1]) relieved_bore(socket_id, collar_h + 2);
        bore_leadin(socket_id, collar_h);
        // M6 anti-slip pin, drilled through the pipe too. Runs along X
        // at y=0, i.e. through the open gap between the plates.
        translate([0, 0, pin_z]) rotate([0, 90, 0])
            cylinder(d = pin_d, h = 200, center = true);
        // pivot and index holes, both sides
        for (s = [1, -1]) scale([s, 1, 1]) {
            translate([boss_x, 0, boss_z]) rotate([90, 0, 0])
                cylinder(d = pivot_d, h = 200, center = true);
            translate([boss_x + index_r * cos(index_a), 0,
                       boss_z + index_r * sin(index_a)])
                rotate([90, 0, 0])
                    cylinder(d = index_d, h = 200, center = true);
        }
    }
}

// ============================================================
// PART 3 : OUTRIGGER ARM  (prints socket-up, no support)
// Local frame: pivot at the origin, pipe socket along +Z, so the
// strut load runs straight down the build direction and presses
// the layers together instead of peeling them.
// ============================================================
neck_r    = pr + 5;               // where the tube may start: clear of
                                  // the clamp's pivot head
neck_hw   = socket_od / 2;        // neck as wide as the tube: no ledge
flat_z    = -pr * cos(45);        // flat base, all overhangs >=45deg

module arc_slot(r, w, ang) {
    rotate_extrude(angle = ang, $fn = 96)
        translate([r - w / 2, 0]) square(w);
}
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

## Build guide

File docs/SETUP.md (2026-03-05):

# セットアップ手順

ビニールハウス自動開閉制御システム

> このドキュメントは Claude（Anthropic）の支援を受けて作成しました。

---

## 前提条件

- Raspberry Pi に **Raspberry Pi OS (Trixie)** がインストール済み
- インターネット接続済み
- `sudo` 権限あり
- I2C を有効化済み（手順は下記「0-b」参照）

> **Trixie と GPIO ライブラリについて**
>
> 2025年以降、Raspberry Pi OS の標準リリースは Trixie (Debian 13) になりました。
> Trixie 環境では従来よく使われていた `pigpio` が **実質使用不可**です：
>
> - **Pi 5 で動作しない（アーキテクチャ的問題）**: Pi5 は BCM2712 + **RP1 サウスブリッジ**構成で、GPIO を管理するのは RP1 チップ。pigpio は `/dev/mem` 経由の DMA 直アクセスを前提としており、この設計が RP1 構成では根本的に機能しない。pigpio 開発者は Pi5 対応を「互換性を壊さずには不可能かもしれない巨大なタスク」と GitHub Issue で明言しており、ロードマップなし（[#589](https://github.com/joan2937/pigpio/issues/589)）
> - **Trixie でビルド不可（Python の問題）**: pigpio の `setup.py` が `distutils` に依存。Python 3.12 で `distutils` が標準ライブラリから削除された。Trixie には代替の `python3-distutils` パッケージもなく、ビルドが通らない
> - **メンテナンス停滞**: 上記問題を抱えたまま更新が止まっており、今後の解決も見込めない
>
> 本システムはこれらを踏まえ、ライブラリに依存しないカーネル標準の
> **sysfs PWM インターフェース**を採用しています。
> （参考スレッド: https://forums.raspberrypi.com/viewtopic.php?t=392438 ）

---

## 0-a. ハードウェア PWM の有効化（必須）

GPIO18 でハードウェア PWM を使うために、起動設定ファイルに `dtoverlay=pwm` を追加します。

```bash
sudo nano /boot/firmware/config.txt
```

末尾に以下を追記：

```
# ハードウェアPWM有効化 (GPIO18=PWM0)
dtoverlay=pwm
```

追記後、再起動：

```bash
sudo reboot
```

再起動後に確認：

```bash
ls /sys/class/pwm/pwmchip0
# → export  npwm  power  subsystem  uevent が表示されれば OK
```

> **なぜ sysfs PWM を使うのか**
>
> `pigpio` は以下の理由で Trixie / Pi5 では使用不可です：
>
> | 問題 | 原因 |
> |------|------|
> | Pi5 で動作しない | Pi5 は BCM2712 + **RP1 サウスブリッジ**構成。GPIO を管理するのは RP1 であり、pigpio が依存する `/dev/mem` 経由の DMA アクセスが機能しない。pigpio 開発者自身が「互換性を壊さずには不可能かもしれない」と明言し、Pi5 対応ロードマップなし |
> | Trixie でビルド不可 | pigpio の `setup.py` が `distutils` に依存。Python 3.12 で `distutils` が標準ライブラリから削除され、Trixie には代替パッケージもない |
> | メンテナンス事実上終了 | 上記問題を抱えたまま更新停止状態 |
>
> カーネルの PWM サブシステム (`/sys/class/pwm/`) を直接操作する方式はライブラリ依存がなく、Pi4・Pi5 両方で動作します。
>
> **Trixie 以降での GPIO ライブラリ全体像（参考）:**
>
> | ライブラリ | Pi4 | Pi5 | PWM | 用途 |
> |-----------|:---:|:---:|-----|------|
> | `pigpio` | ○ | **×** | ハードウェア | 実質廃止 |
> | `RPi.GPIO` | ○ | △ | ソフトのみ | 非推奨移行中（Pi5は非公式） |
> | `rpi-lgpio` | ○ | ○ | ソフトのみ | RPi.GPIO の drop-in 代替 |
> | `lgpio` | ○ | ○ | ソフトのみ | Raspberry Pi 公式推奨 |
> | `gpiozero` | ○ | ○ | ソフトのみ | 公式推奨（lgpio バックエンド） |
> | `python-gpiod` | ○ | ○ | なし | Linux 標準 GPIO のみ |
> | **sysfs PWM** | **○** | **○** | **ハードウェア** | **精度 PWM に最善** |
>
> モータ制御のように精度が必要な PWM には、現時点では **sysfs ハードウェア PWM が最も安定**しています。
>
> **Pi5 利用者へ**: `RPi.GPIO` の代わりに `pip install rpi-lgpio` をインストールすると、コードを変更せずに GPIO 方向制御を Pi5 でも動作させられます。`pwmchip0` は Pi4・Pi5 とも `dtoverlay=pwm` で同様に使用できます。
>
> ※現時点 2026/03 での情報です。詳しい背景情報は作者(iga)も正しく把握できていません。

---

## 0-b. I2C の有効化（必須）

センサ（SEN0501 / SCD41）は I2C 接続のため、有効化が必要です。

```bash
sudo raspi-config
```

`raspi-config` のメニューで操作：

```
3 Interface Options
  → I5 I2C
    → Yes（有効化）
    → OK
```

設定後に再起動（PWM 設定と同時に行う場合は一度でまとめて OK）：

```bash
sudo reboot
```

再起動後に確認：

```bash
i2cdetect -y 1
# → 0x22（SEN0501）と 0x62（SCD41）が表示されれば OK
```

---

## 1. Python 依存ライブラリのインストール

Trixie（Python 3.12）では `pip` のシステム全体インストールが制限されています。
`sudo` で強制インストールするか、仮想環境を使います。

**方法 A（推奨）: `--break-system-packages` フラグで直接インストール**

```bash
sudo pip install RPi.GPIO adafruit-circuitpython-scd4x dfrobot-environmental-sensor --break-system-packages
```

> systemd サービスが `User=root` で動作するため、root の環境にインストールする必要があります。
> venv を使う場合は systemd の `ExecStart` を venv のパスに変更してください。

**方法 B: venv を使う場合**

```bash
sudo python3 -m venv /opt/house-controller/.venv
sudo /opt/house-controller/.venv/bin/pip install RPi.GPIO adafruit-circuitpython-scd4x dfrobot-environmental-sensor
```

venv を使う場合は後述の systemd サービスの `ExecStart` を以下に変更：

```
ExecStart=/opt/house-controller/.venv/bin/python3 /opt/house-controller/metrics_server.py
```

---

## 2. ファイルの配置

```bash
# 任意のディレクトリに配置（例: /opt/house-controller）
sudo mkdir -p /opt/house-controller
sudo cp metrics_server.py /opt/house-controller/
sudo cp motor_server.py /opt/house-controller/
```

---

## 3. systemd サービスの設定

### metrics_server（センササーバ）

```bash
sudo nano /etc/systemd/system/metrics_server.service
```

```ini
[Unit]
Description=House Metrics Server
After=network.target

[Service]
ExecStart=/usr/bin/python3 /opt/house-controller/metrics_server.py
Restart=always
RestartSec=5
User=root

[Install]
WantedBy=multi-user.target
```

### motor_server（モータ制御サーバ）

```bash
sudo nano /etc/systemd/system/motor_server.service
```

```ini
[Unit]
Description=House Motor Server
After=network.target

[Service]
ExecStart=/usr/bin/python3 /opt/house-controller/motor_server.py
Restart=always
RestartSec=5
User=root

[Install]
WantedBy=multi-user.target
```

### サービスの有効化・起動

```bash
sudo systemctl daemon-reload
sudo systemctl enable metrics_server motor_server
sudo systemctl start metrics_server motor_server

# 動作確認
sudo systemctl status metrics_server
sudo systemctl status motor_server
```

---

## 4. 動作確認（ローカル）

```bash
# センサデータの確認
curl http://127.0.0.1:8124/metrics

# モータサーバのヘルスチェック
curl http://127.0.0.1:8125/health

# モータ動作テスト（開く方向、5秒、duty 50%）
curl "http://127.0.0.1:8125/run?dir=0&sec=5&duty=50"

# 緊急停止
curl http://127.0.0.1:8125/stop
```

---

## 5. Docker / Home Assistant のセットアップ

### Docker インストール

```bash
curl -sSL https://get.docker.com | sh
sudo usermod -aG docker $USER
```

### Home Assistant 起動

```bash
docker run -d \
  --name homeassistant \
  --restart unless-stopped \
  --network host \
  -v /home/$USER/ha_config:/config \
  ghcr.io/home-assistant/home-assistant:stable
```

### Home Assistant 設定の適用

`HomeAssistantConfiguration.yaml` の内容を `/home/$USER/ha_config/configuration.yaml` に追記または上書きします。

```bash
cp HomeAssistantConfiguration.yaml ~/ha_config/configuration.yaml
```

その後 Home Assistant を再起動：

```bash
docker restart homeassistant
```

---

## 6. Cloudflare Tunnel の設定

### 6.1 ドメインの取得（必須）

Cloudflare Tunnel を使うには独自ドメインが必要です。
Cloudflare でドメインを登録・管理すると Tunnel との連携がスムーズです。

**コスト例（Cloudflare Registrar）:**

| TLD | 年額（目安） |
|-----|---|
| `.party` | 約 $4 / 年 ← 最安クラス |
| `.com` | 約 $10 / 年 |
| `.dev` | 約 $12 / 年 |

> `.party` ドメインが現状(2026/03/03)で最安クラスです。
> Cloudflare Registrar は原価販売のため更新料も同額です。

**手順:**
1. [Cloudflare](https://www.cloudflare.com/) にアカウント登録
2. `Domain Registration` → `Register Domains` でドメインを検索・購入
3. 購入後、自動的に Cloudflare DNS で管理される
※もっと安いのがあればすみません。なお無料でやる方法もありますが、手順がまあまあ伸びるので端折ります。

### 6.2 cloudflared のインストール（Raspberry Pi 上）

**root `ro` 化より前に実施すること。**

```bash
# Cloudflare GPG キーを追加
sudo mkdir -p --mode=0755 /usr/share/keyrings
curl -fsSL https://pkg.cloudflare.com/cloudflare-main.gpg | sudo tee /usr/share/keyrings/cloudflare-main.gpg >/dev/null

# apt リポジトリを追加
echo 'deb [signed-by=/usr/share/keyrings/cloudflare-main.gpg] https://pkg.cloudflare.com/cloudflared any main' | sudo tee /etc/apt/sources.list.d/cloudflared.list

# インストール
sudo apt-get update && sudo apt-get install cloudflared
```

> root `ro` 化後にアップデートする場合は `sudo mount -o remount,rw /` で一時的に rw に戻してから実施してください。

### 6.3 Tunnel の作成と設定

1. [Cloudflare Zero Trust](https://one.dash.cloudflare.com/) にログイン
2. `Networks` → `Connectors` → `Create a Tunnel` → `Cloudflared` を選択
3. Tunnel 名を入力
4. **「Install and run a connector」** の画面に表示されるコマンドを Raspberry Pi で実行

   ```bash
   # 表示されるコマンド例（トークンは各自異なる）
   sudo cloudflared service install <YOUR_TUNNEL_TOKEN>
   ```

   > このコマンドで cloudflared が systemd サービスとして登録・起動されます。

5. Tunnel のルーティング設定：
   - **Service**: `http://localhost:8123`
   - **Domain**: 取得したドメインのサブドメイン（例: `ha.yourdomain.party`）

6. `HomeAssistantConfiguration.yaml` の `external_url` を設定した URL に変更して HA を再起動

### 6.4 動作確認

```bash
# cloudflared サービスの状態確認
sudo systemctl status cloudflared

# ブラウザまたはスマートフォンから設定した URL にアクセスして HA が表示されれば OK
```

---

## 7. USB 分離構成（root ro 化時は必須・推奨）

root を ro 化している場合は Docker・HA・cloudflared データの USB 分離が必須です（ro のまま書き込めないため）。
SD カードの長寿命化にも効果があります。
手順は [src/ROM_USB_MIGRATION_PLAN.md](../src/ROM_USB_MIGRATION_PLAN.md) を参照してください。

---

## トラブルシューティング

| 症状 | 確認事項 |
|---|---|
| センサ値が取れない | `i2cdetect -y 1` で 0x22 / 0x62 が見えるか確認 |
| モータが動かない | GPIO18 / GPIO23 の配線・MDD10 の電源を確認 |
| PWM が動作しない | `ls /sys/class/pwm/pwmchip0` でディレクトリが存在するか確認。なければ `dtoverlay=pwm` が未設定 |
| HA から REST が失敗する | `curl http://127.0.0.1:8125/health` を Raspberry Pi 上で実行 |
| SCD41 が `null` を返す | 起動直後は `data_ready` が false。数秒待ってから再取得 |
| cloudflared が起動しない | `sudo systemctl status cloudflared` でログ確認。トークンが正しいか再確認 |
| pip install が失敗する | `--break-system-packages` フラグを追加、または venv を使用 |
| **Pi5 でモータが動かない（GPIO エラー）** | RPi.GPIO は Pi5 非公式。`pip install rpi-lgpio --break-system-packages` を追加インストールすると drop-in 代替として動作する |
| **Pi5 で pigpio エラー** | pigpio は Pi5 非対応（RP1 チップの DMA 互換性なし）。本システムは pigpio を使用していないため通常は出ないが、出た場合は pigpio の残骸を削除する |

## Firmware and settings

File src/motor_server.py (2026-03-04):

#!/usr/bin/env python3
import json
import os
import time
from http.server import BaseHTTPRequestHandler, HTTPServer
from urllib.parse import urlparse, parse_qs

import RPi.GPIO as GPIO

# ==== GPIO/PWM settings ====
DIR_GPIO = 23          # BCM
PWM_CHIP = "/sys/class/pwm/pwmchip0"
PWM_CH = 0             # PWM0 -> GPIO18
PWM_PATH = f"{PWM_CHIP}/pwm{PWM_CH}"

# 20kHz（MDD10推奨帯域）
PWM_FREQ_HZ = 20000
PWM_PERIOD_NS = int(1e9 / PWM_FREQ_HZ)

# フェイルセーフ
MAX_SECONDS = 900      # 暴走防止（最大15分）
DEFAULT_DUTY = 100     # 0-100

LOCK_FILE = "/run/house-motor.lock"


def _write(path: str, s: str) -> None:
    with open(path, "w") as f:
        f.write(s)


def pwm_export_if_needed():
    if not os.path.isdir(PWM_PATH):
        _write(f"{PWM_CHIP}/export", str(PWM_CH))
        # udev反映待ち
        for _ in range(50):
            if os.path.isdir(PWM_PATH):
                break
            time.sleep(0.05)


def pwm_setup():
    pwm_export_if_needed()
    _write(f"{PWM_PATH}/period", str(PWM_PERIOD_NS))
    _write(f"{PWM_PATH}/duty_cycle", "0")
    _write(f"{PWM_PATH}/enable", "0")


def pwm_set_duty(duty_percent: int):
    duty_percent = max(0, min(100, duty_percent))
    duty_ns = int(PWM_PERIOD_NS * duty_percent / 100)
    _write(f"{PWM_PATH}/duty_cycle", str(duty_ns))


def pwm_enable(enable: bool):
    _write(f"{PWM_PATH}/enable", "1" if enable else "0")


def motor_stop():
    pwm_set_duty(0)
    pwm_enable(False)


def acquire_lock() -> bool:
    try:
        fd = os.open(LOCK_FILE, os.O_CREAT | os.O_EXCL | os.O_WRONLY, 0o644)
        os.write(fd, str(os.getpid()).encode())
        os.close(fd)
        return True
    except FileExistsError:
        return False


def release_lock():
    try:
        os.unlink(LOCK_FILE)
    except FileNotFoundError:
        pass


def motor_run(direction: int, seconds: int, duty: int):
    """
    direction: 0/1
    seconds: run time
    duty: 0-100
    """
    seconds = max(0, min(MAX_SECONDS, seconds))
    duty = max(0, min(100, duty))

    if not acquire_lock():
        return {"ok": False, "error": "busy"}

    try:
        GPIO.setmode(GPIO.BCM)
        GPIO.setwarnings(False)
        GPIO.setup(DIR_GPIO, GPIO.OUT)
        GPIO.output(DIR_GPIO, GPIO.HIGH if direction else GPIO.LOW)

        pwm_setup()
        pwm_set_duty(duty)
        pwm_enable(True)

        t0 = time.time()
        while time.time() - t0 < seconds:
            time.sleep(0.05)

        motor_stop()
        return {"ok": True, "direction": direction, "seconds": seconds, "duty": duty}
    finally:
        try:
            motor_stop()
        except Exception:
            pass
        GPIO.cleanup(DIR_GPIO)
        release_lock()


class Handler(BaseHTTPRequestHandler):
    def _send(self, code: int, payload: dict):
        body = json.dumps(payload).encode("utf-8")
        self.send_response(code)
        self.send_header("Content-Type", "application/json; charset=utf-8")
        self.send_header("Content-Length", str(len(body)))
        self.end_headers()
        self.wfile.write(body)

    def do_GET(self):
        u = urlparse(self.path)
        qs = parse_qs(u.query)

        # /health
        if u.path == "/health":
            self._send(200, {"ok": True})
            return

        # /stop
        if u.path == "/stop":
            try:
                motor_stop()
            except Exception:
                pass
            release_lock()
            self._send(200, {"ok": True})
            return

        # /run?dir=0|1&sec=10&duty=100
        if u.path == "/run":
            try:
                direction = int(qs.get("dir", ["0"])[0])
                seconds = int(qs.get("sec", ["0"])[0])
                duty = int(qs.get("duty", [str(DEFAULT_DUTY)])[0])
            except Exception:
                self._send(400, {"ok": False, "error": "bad_params"})
                return

            if direction not in (0, 1):
                self._send(400, {"ok": False, "error": "dir_must_be_0_or_1"})
                return

            result = motor_run(direction, seconds, duty)
            code = 200 if result.get("ok") else 409
            self._send(code, result)
            return

        self._send(404, {"ok": False, "error": "not_found"})

    def log_message(self, fmt, *args):
        # systemd/journaldに任せる（静音化）
        return


def main():
    server = HTTPServer(("0.0.0.0", 8125), Handler)
    server.serve_forever()


if __name__ == "__main__":
    main()

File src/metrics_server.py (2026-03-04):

#!/usr/bin/env python3
import json
import time
from http.server import BaseHTTPRequestHandler, HTTPServer

# SEN0501 (I2C 0x22)
from dfrobot_environmental_sensor import EnvironmentalSensor, Units, UVSensor

# VOL-23 / SCD41 (I2C 0x62)
import board
import adafruit_scd4x

I2C_BUS = 1
SEN0501_ADDR = 0x22
HTTP_PORT = 8124

# SEN0501: UV/照度/気圧は使わないが、初期化にUVバリアント指定が必要な場合がある
# （V2系はLTR390UVが一般的）
_sen = EnvironmentalSensor.i2c(bus=I2C_BUS, address=SEN0501_ADDR, uv_sensor=UVSensor.LTR390UV)

_i2c = board.I2C()  # /dev/i2c-1 を使用
_scd4x = adafruit_scd4x.SCD4X(_i2c)
_scd4x.start_periodic_measurement()


def read_sen0501_temp_hum():
    # 温湿度のみ取得（他は呼ばない）
    t = float(_sen.read_temperature(Units.C))
    h = float(_sen.read_humidity())
    return {"temperature_c": round(t, 2), "humidity_rh": round(h, 2)}


def read_scd41():
    # data_readyで取れる時だけ返す（起動直後はNoneになり得る）
    if not _scd4x.data_ready:
        return None
    return {
        "co2_ppm": int(_scd4x.CO2),
        "temperature_c": round(float(_scd4x.temperature), 2),
        "humidity_rh": round(float(_scd4x.relative_humidity), 2),
    }


def read_all():
    return {
        "timestamp": int(time.time()),
        "sen0501": read_sen0501_temp_hum(),
        "scd41": read_scd41(),
    }


class Handler(BaseHTTPRequestHandler):
    def do_GET(self):
        if self.path not in ("/", "/metrics"):
            self.send_response(404)
            self.end_headers()
            return

        payload = read_all()
        body = json.dumps(payload, ensure_ascii=False).encode("utf-8")

        self.send_response(200)
        self.send_header("Content-Type", "application/json; charset=utf-8")
        self.send_header("Content-Length", str(len(body)))
        self.end_headers()
        self.wfile.write(body)

    def log_message(self, fmt, *args):
        return  # ログ不要


def main():
    HTTPServer(("0.0.0.0", HTTP_PORT), Handler).serve_forever()


if __name__ == "__main__":
    main()

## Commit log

2026-08-25 Add 3D-printable demo stand parts for maker faire greenhouse opener
    Parametric OpenSCAD design (22.2mm greenhouse pipe) for a P1S/PLA
    printable foot, pole clamp, and adjustable-angle outrigger arm to
    stabilize the demo rig's stand at the maker faire.
    [arm.stl, foot.stl, pole_clamp.stl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]
2026-08-25 Demo stand rev.2: two-sided fork clamp, reworked for printability
    One pole_clamp now carries both the fore and aft outrigger arms:
    the single side boss is replaced by a pair of parallel plates that
    straddle the pole and reach out to both sides, holding each arm in
    double shear. The pole passes right through, so the clamp can sit
    at any height rather than only at the top.
    Reshaped every part around its print orientation: flat bases on the
    plate, no support anywhere, all downward faces at 45 degrees or
    steeper, and the strut load pressed across the layers in compression
    instead of peeling them. Vertical socket bores print round; the
    foot's underside recess is gone for better adhesion and less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
    [arm.stl, foot.stl, pole_clamp.stl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]
2026-09-01 Add roll-up drive fixtures for the 5840-31ZY motor
    Motor changed to a uxcell/5840-31ZY DC12V 30RPM worm gear motor with
    an 8mm D output shaft, driving a 19mm winding pipe off 22mm posts.
    Three parts, all printing standing on the collar axis with a flat
    base and no support:
    motor_plate 22mm post collar plus a flat plate the gearbox
    bolts to. The motor's M4 pitch is not published, so
    the plate uses eight radial slots covering any
    pattern with a 15-28mm half-diagonal, plus strap
    slots to zip-tie the gearbox as a fallback.
    bearing_block 22mm post collar with a plain journal for the 19mm
    pipe. The journa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
    [bearing_block.stl, coupler.stl, motor_parts.scad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]
